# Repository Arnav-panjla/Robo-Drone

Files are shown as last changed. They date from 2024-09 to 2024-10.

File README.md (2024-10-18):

# Drone Project 🚀

Welcome to the Drone Project, developed by the Robotics Club at IIT Delhi. This project showcases a fully custom drone built from scratch, featuring 3D-printed chassis, custom motor drivers, and a custom remote controller.
  <br>
  <br>
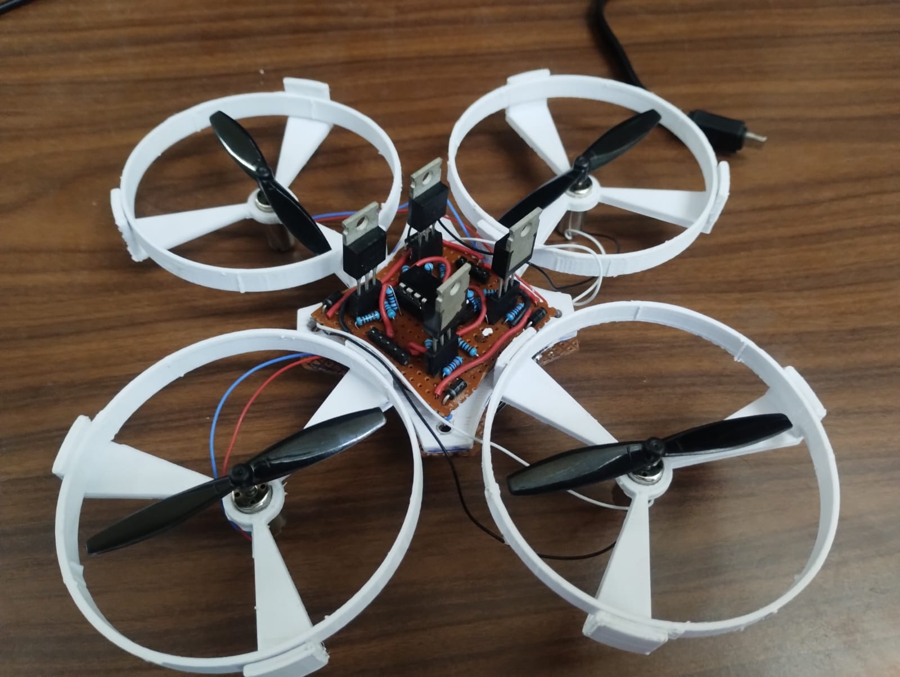
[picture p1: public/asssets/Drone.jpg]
Drone
  
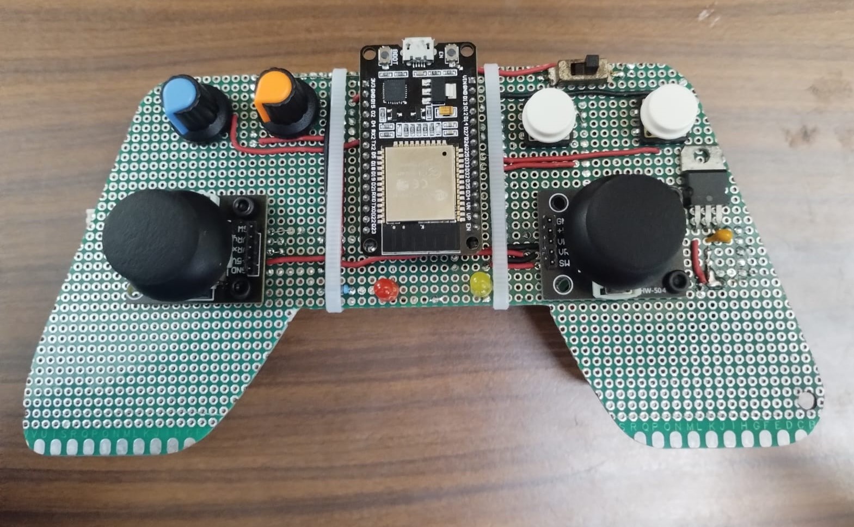
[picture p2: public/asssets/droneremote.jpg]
Motor Driver
  
  <br>

## Table of Contents 📚
- [Introduction](https://github.com/Arnav-panjla/Robo-Drone/blob/main/README.md#introduction-)
- [Components](https://github.com/Arnav-panjla/Robo-Drone/blob/main/README.md#components-%EF%B8%8F)
- [Design and Architecture](https://github.com/Arnav-panjla/Robo-Drone/blob/main/README.md#design-and-architecture-%EF%B8%8F)
- [Functionality](https://github.com/Arnav-panjla/Robo-Drone/blob/main/README.md#functionality-%EF%B8%8F)
- [Theory Used](https://github.com/Arnav-panjla/Robo-Drone/blob/main/README.md#theory-used-)
- [Usage](https://github.com/Arnav-panjla/Robo-Drone/blob/main/README.md#usage-)
- [Contributions](https://github.com/Arnav-panjla/Robo-Drone/blob/main/README.md#contributions-)
- [License](https://github.com/Arnav-panjla/Robo-Drone/blob/main/README.md#license-)
- [Acknowledgements](https://github.com/Arnav-panjla/Robo-Drone/blob/main/README.md#acknowledgements-)

## Introduction 🌟

The drone is designed to be a versatile platform for exploring robotics, remote control, and sensor integration. At its core, the drone utilizes an ESP32-C3 module for communication and control, enabling advanced features such as PID control and integration with a BMX160 sensor for enhanced stability and performance.

## Components 🛠️

- **Chassis**: 3D-printed design for a lightweight and durable structure.
- **Microcontroller**: Xiao ESP32-C3 for receiving signals and controlling motors.
- **Motor Drivers**: Custom-built motor drivers using operational amplifiers (op-amps) and N-channel MOSFETs.
- **Remote Controller**: Built with an ESP32, joystick module, and switches for intuitive control.
- **Sensors**: PID controller and BMX160 sensor for improved stability and performance.

## Design and Architecture 🖥️

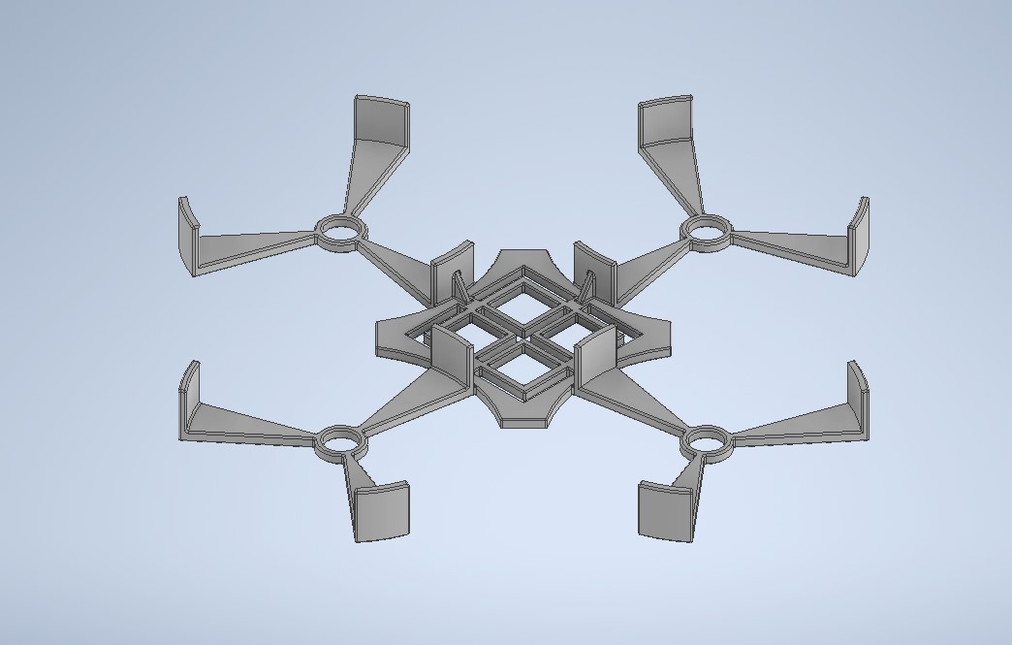
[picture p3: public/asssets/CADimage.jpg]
CADimage


- **Communication**: The drone and remote controller communicate via Wi-Fi, utilizing the ESP32’s capabilities.
- **Motor Control**: PWM signals generated by the ESP32 are amplified by op-amps and used to drive the motors through N-channel MOSFETs.
- **Control Logic**: Implemented PID control for precise maneuvering and stability.
- **posotion calibration**: Done by BMX160 measurment and subsequently using kalman filter.

## Functionality ✈️

- **Remote Control**: Control the drone using a joystick and switches on the remote controller.
- **Stability and Responsiveness**: Utilizes PID control and BMX160 sensor feedback filtered thruogh kalman filter to maintain stable flight.
- **Customizability**: Fully customizable components for future modifications and enhancements.

## Theory Used 📚

In addition to fundamental principles of electronics and mechanics, several advanced concepts were utilized in the development of this project:

- **PID Control**
- **Kalman Filter**
- **PCB designing**
- **Quadcopter Mechanics**
- **3D Design**
- **ESP32 Wi-Fi Communication**

These theories and technologies collectively contributed to the successful implementation and performance of the drone project.

## Usage 📡

1. Power on the drone and remote controller.
2. Connect the remote controller to the drone's Wi-Fi network.
3. Use the joystick remote to control the drone's movements.

## Contributions 🤝

We welcome contributions from anyone interested in enhancing this project! To contribute:

## License 📜

This project is licensed under the MIT License. See the [LICENSE](LICENSE) file for more details.

## Acknowledgements 🙏

- Special thanks to the Robotics Club at IIT Delhi for their support and collaboration.
- I would like to thank the following friends for their invaluable help in building this repository:
    - [Lakshay Bhatnagar](https://github.com/Lakshya-bh) 
    - [Rishima Chaturvedi](https://github.com/friendusername)
- Inspired by various open-source projects in the robotics community.

---

Feel free to reach out if you have any questions or need assistance! 😊

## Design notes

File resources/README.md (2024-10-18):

# Resources 📚

This section contains useful resources, including datasheets and manuals for the components used in the Drone Project.

## Internal Links 🔗

- **LM324 1GHz Opamp**: [LM324 Datasheet](./LM324.PDF)
  <br>
  <br>
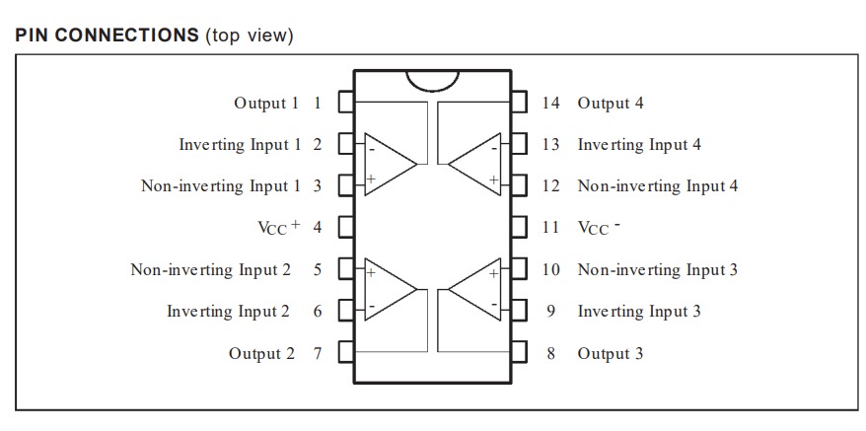
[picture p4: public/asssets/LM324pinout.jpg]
ESP32 Pinout
  

- **IRFZ44N n-channel mosfet**: [IRFZ444N Datasheet](./IRFZ44N.PDF)
  <br>
  <br>
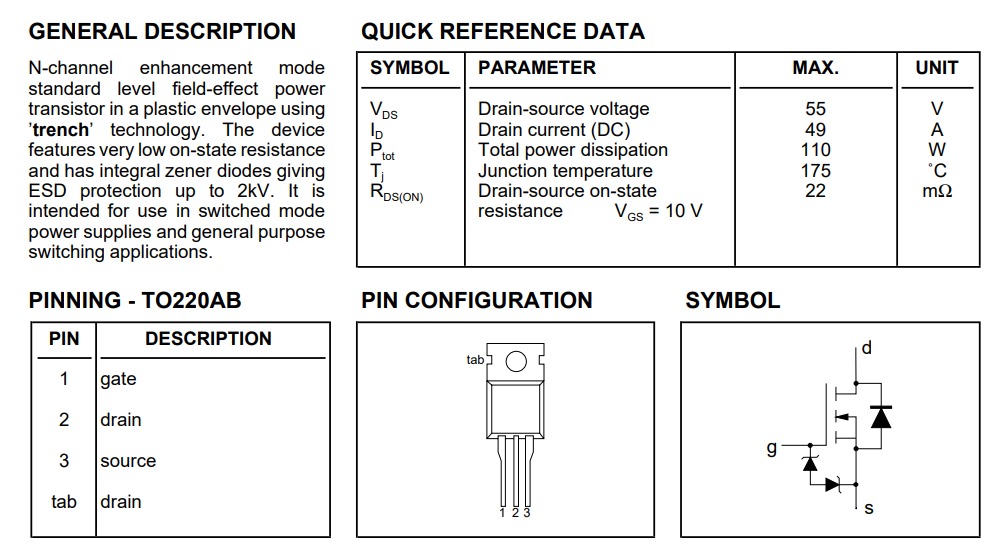
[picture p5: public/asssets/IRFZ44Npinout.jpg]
ESP32 Pinout
  

- **BMX160 Sensor Datasheet**: [BMX160 Sensor Datasheet](./BMX160datasheet.pdf)

## External Links 🌐

- **ESP32**:  [offical espressif ESP32 Manual](https://www.espressif.com/en/products/devkits/esp32-devkitc)
  <br>
  <br>
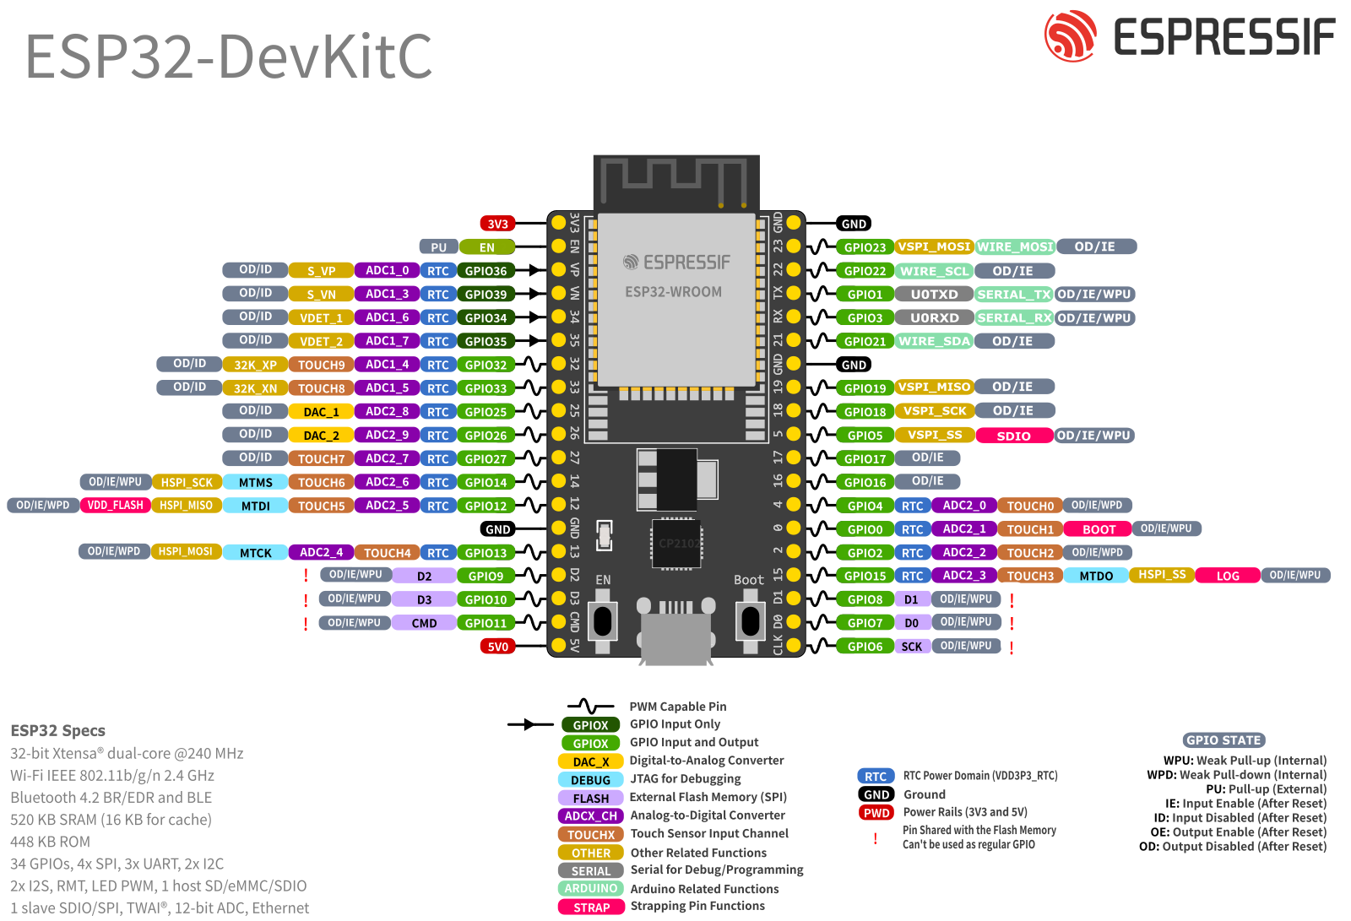
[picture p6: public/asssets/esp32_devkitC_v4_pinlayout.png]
  

- **ESP32-C3**:  [offical XiaoESP32C3 Manual](https://wiki.seeedstudio.com/XIAO_ESP32C3_Getting_Started/)
  <br>
  <br>
ESP32-C3 Pinout
  

- **Oscilloscope Manual**: [Oscilloscope User Manual](./sds5032ev_user_manual.pdf)

- **PID Control Theory**: to be added

## Additional Resources 📖

- **Remote Design**: [How to mechatronics custom rc controller project](https://howtomechatronics.com/projects/diy-arduino-rc-receiver/)

Feel free to explore these resources to enhance your understanding and capabilities in working with the Drone Project!

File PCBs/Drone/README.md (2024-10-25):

#  Drone Driver Circuit

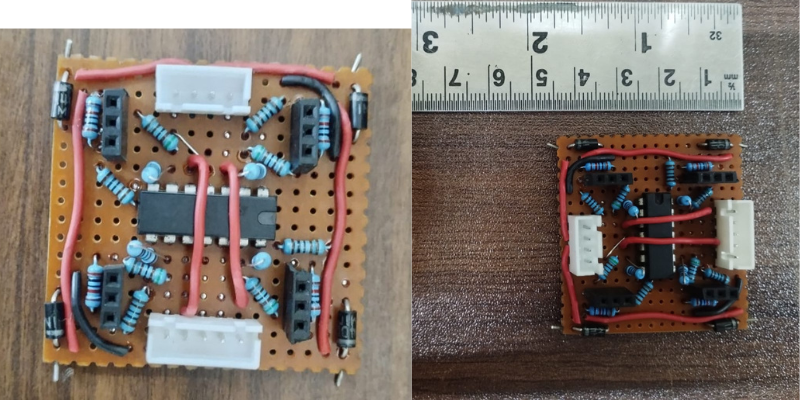
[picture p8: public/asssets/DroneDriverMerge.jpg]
Motor Driver


<!-- ## 📚 Table of Contents
1. [Introduction](#introduction)
2. [Necessity of Creating the Motor Driver](#necessity-of-creating-the-motor-driver)
3. [Testing Video](#testing-video)
4. [Circuit Overview](#circuit-overview)
   - [Motor Driver Circuit](#motor-driver-circuit)
   - [Complete Circuit with ESP32](#complete-circuit-with-esp32)
5. [Components List](#components-list)
6. [Schematic Diagrams](#schematic-diagrams)
   - [Motor Driver Circuit Schematic](#motor-driver-circuit-schematic)
   - [Complete Circuit Schematic](#complete-circuit-schematic)
7. [Connections and Pinouts](#connections-and-pinouts)
8. [Operation and Safety Precautions](#operation-and-safety-precautions)
9. [Future Improvements](#future-improvements)
10. [References](#references) -->

---

## 1. 📝 Introduction

This README provides detailed information about the motor driver circuit designed for controlling four propellers of a drone using an ESP32 microcontroller. The motor driver circuit can handle up to 3.3A at maximum load and operates a 3.7V motor in a single direction.

---

## 2. 🛠️ Necessity of Creating the Motor Driver
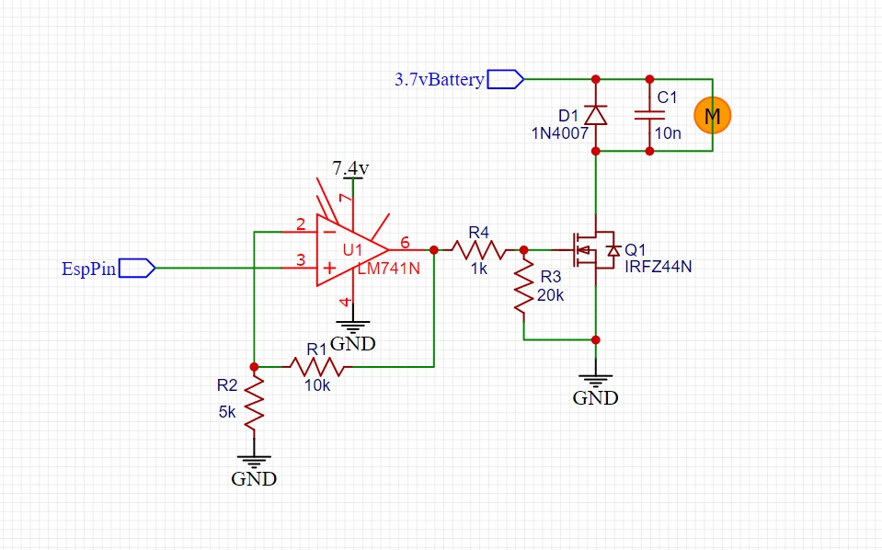
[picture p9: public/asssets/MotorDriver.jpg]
Motor Driver

<br>
The development of this motor driver circuit is essential for several reasons:

- **High Current Handling**: This motor driver can handle up to 3.3A, which is unmatched by other drivers in the market within this price range, making it an economical yet powerful solution for drone applications.

- **Optimization for Drones**: The design is fully optimized for drone operations, ensuring efficient control of the motors under varying loads and conditions.

- **Signal Amplification**:
  <br>
  <br>
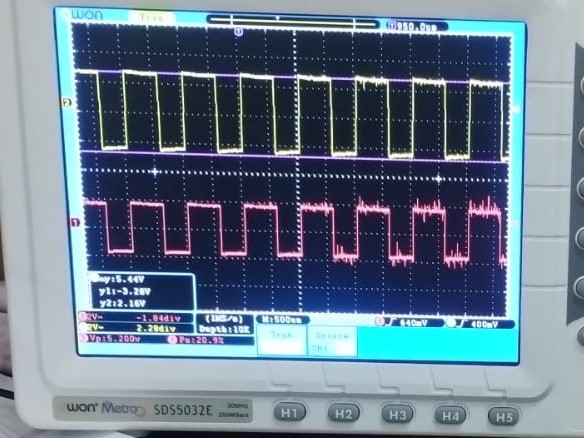
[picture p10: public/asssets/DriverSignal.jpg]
Motor Driver
  
  <br>
 The 3.3V output from the ESP32 was insufficient to drive the MOSFETs directly. To address this, we incorporated an operational amplifier (op-amp) with a non-inverting gain of 1.5. This setup amplifies the 3.3V signal to approximately 5V, effectively driving the MOSFETs and consequently powering the drone motors.

---

## 3. 🎥 Testing Video

To see the motor driver in action, check out the video of our testing process:

[Watch the Testing Video](..\..\public\asssets\DriverTestingVideo.mp4")

In this video, we demonstrate the operation of the motor driver, showcasing its performance and the control of the drone motors.

---

## 4. ⚙️ Circuit Overview

### Motor Driver Circuit: [Motor Driver Schematics PDF](./MotorDriverSchematics.pdf)

The motor driver circuit interfaces with the ESP32 to control the speed and operation of a 3.7V motor. The circuit utilizes MOSFETs or a dedicated motor driver IC for efficient power management.

- **Voltage**: 3.7V and 7.4V for powering op-amps
- **Current**: Up to 3.3A

### Complete Circuit with ESP32 [Motor Driver Schematics PDF](./DroneDriverSchematics.pdf)

The complete circuit integrates the ESP32S# microcontroller, controlling the four motor driver circuits with PWM signals.

---

## 5. 🔧 Components List

| Component | Quantity | Description |
|---|---|---|
| ESP32S3 | 1 | Microcontroller |
| op-AMP | 4 | Part of motor driver circuit |
| N-channel MOSFET | 4 | For motor control |
| Resistors | Various  | Pull-down and for op-amps |
| Capacitors | 4 | Decoupling and filtering |
| Diodes | 4 | Flyback diodes for protection |
| Connectors | Various  | For connecting motors and power |
| Power Supply | 2 | 3.7V batteries |
| PCB | 1 | Custom PCB designed in EasyEDA  |

---

## 6. 📐 Complete Schematic Diagrams

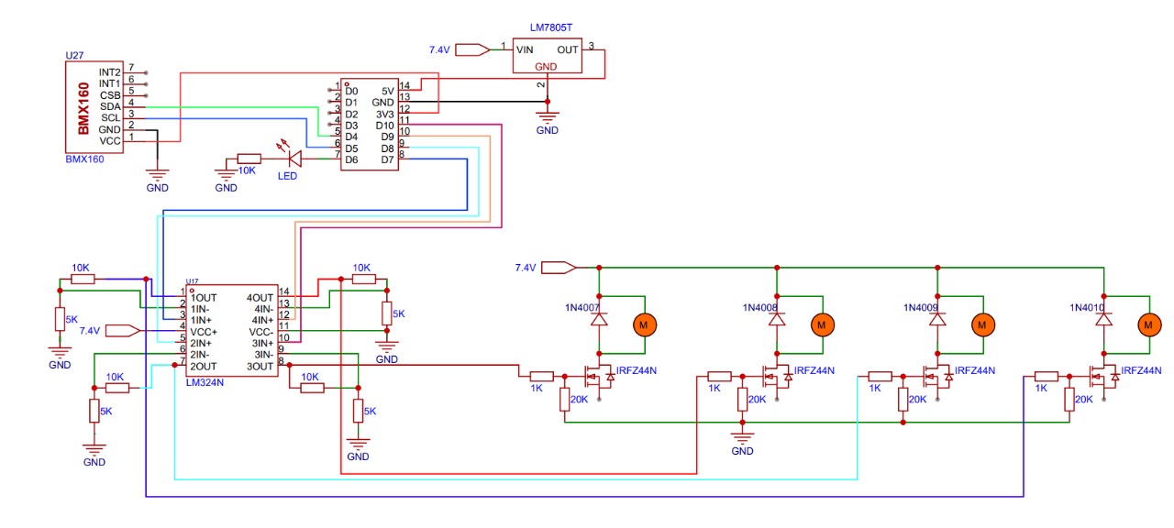
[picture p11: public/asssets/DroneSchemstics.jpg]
Drone Schematics


---

## 7. 🔌 Connections and Pinouts

### ESP32 Pinouts

- **GPIO Pins**: Used for PWM control of the motor drivers.
- **Power Supply**: Connect to the appropriate power source (3.7V).

### Motor Driver Connections

- **Input Pins**: Connect to the corresponding GPIO pins of the ESP32.
- **Motor Terminals**: Connect to the propellers.
- **Power Connections**: Ensure correct voltage and current ratings are followed.

---

## 8. ⚡ Operation and Safety Precautions

- The ESP32 sends PWM signals to the motor drivers to control the speed and operation of each motor.
- Ensure that the code is properly uploaded to the ESP32 to manage motor functions as desired.

### Safety Precautions
- Ensure all connections are secure to prevent shorts.
- Beware of heating of MOSFETs, heatsink not used therefore avoid continuous usage.
- Double-check component ratings to avoid damage.

---

## 9. 🚀 Future Improvements

- Consider adding a speed feedback mechanism for better control.
- Explore options for direction control (e.g., H-bridge configuration).
- Explore professional PCB milling.
- Implement wireless control features using ESP32 capabilities.

---

## 10. 📖 References

- Check out [resources](../../resources/) repository.

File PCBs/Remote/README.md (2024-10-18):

# Remote PCB for Drone Control 🚀
  <br>
  Motor Driver
  <br>

## Overview

This repository contains the design and documentation for a remote PCB used to control a self-made drone. The remote features an ESP32 microcontroller, two joysticks, two potentiometers, two buttons, and onboard LEDs to indicate the success or failure of signal transmission. The system is powered by a 2S battery, with voltage regulation to ensure stable operation.

## Components 🛠️

- **Microcontroller**: ESP32
- **Input Devices**: 
  - 2 Joysticks
  - 2 Potentiometers
  - 2 Buttons
- **LED Indicators**: For success/failure of signal transmission
- **Power Supply**: 
  - 2S LiPo Battery
  - Voltage regulator: LM7806 (step down to 6V) and onboard voltage converter to 3.3V

## Features 🌟

- **Real-time Control**: The joysticks allow for precise control of the drone's movements.
- **Adjustable Parameters**: Potentiometers can be used to adjust flight parameters such as speed and altitude.
- **Status Indication**: Onboard LEDs provide visual feedback on signal status.
- **Compact Design**: Optimized for integration with a drone.

## Schematic 🖼️

  <br>
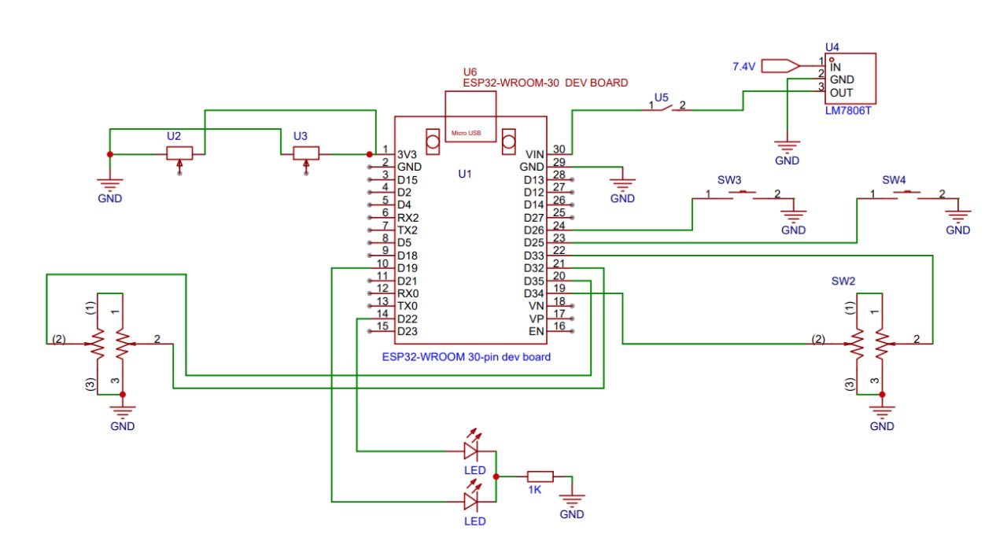
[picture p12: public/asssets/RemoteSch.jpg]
  
  <br>

## Wiring Diagram 🖼️

  <br>
  Motor Driver
  <br>*

## Setup Instructions ⚙️

1. **Power Connection**:
   - Connect a 2S LiPo battery to the power input of the PCB.
   - The LM7806 will step down the voltage to 6V, and the onboard converter will provide 3.3V for the ESP32.

2. **Input Device Connections**:
   - Connect the joysticks and potentiometers to the designated analog input pins on the ESP32.
   - Connect the buttons to digital input pins.

3. **LED Connections**:
   - Connect the LEDs to appropriate GPIO pins for status indication.

4. **Programming the ESP32**:
   - Use the Arduino IDE or PlatformIO to upload the control code to the ESP32.
   - Ensure the necessary libraries for the ESP32 and input devices are installed.

## Usage 🎮

1. Power on the remote by connecting the 2S battery.
2. The onboard LEDs will indicate the power status and signal transmission status.
3. Use the joysticks to control the drone's movements and the potentiometers to adjust flight settings.
4. Press the buttons for additional functionalities (e.g., takeoff, landing).

## Troubleshooting 🔧

- **LEDs Not Lighting Up**: Check power connections and ensure the battery is charged.
- **Signal Transmission Issues**: Verify the connections to the ESP32 and the antennas if used.
- **Unresponsive Inputs**: Ensure that the joysticks and potentiometers are connected properly.

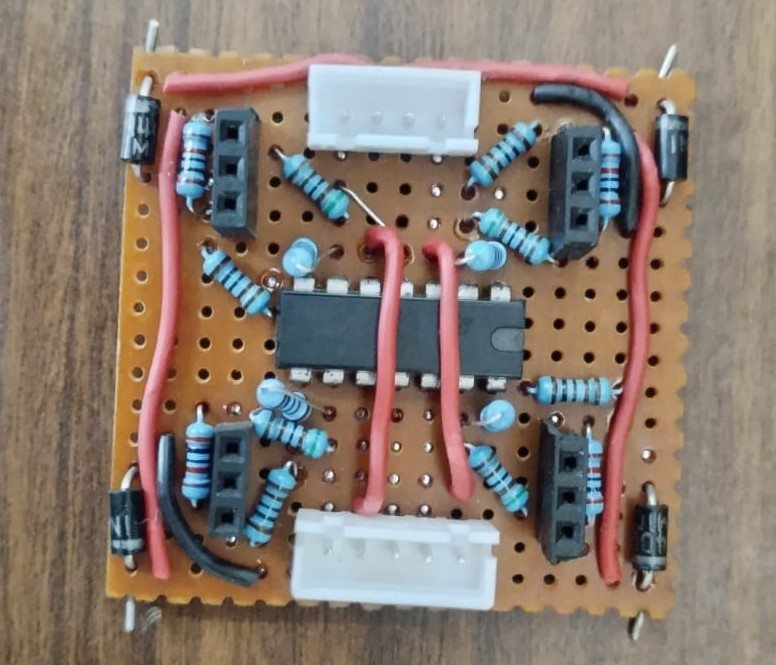
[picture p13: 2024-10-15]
public/asssets/DroneDriver.jpg

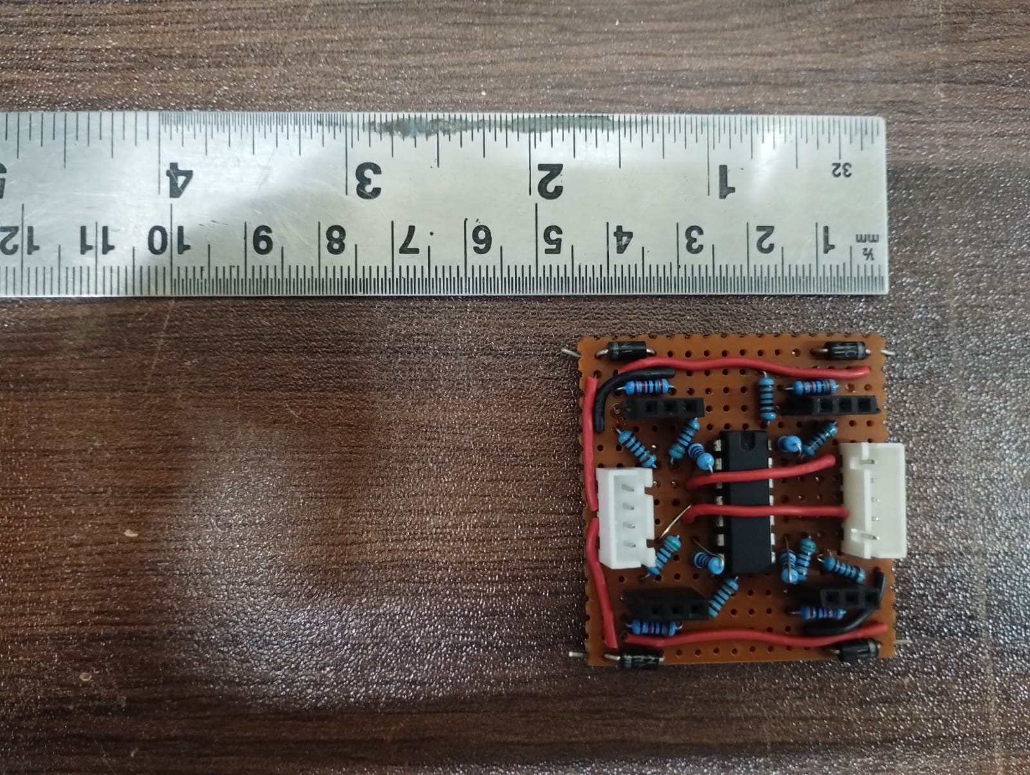
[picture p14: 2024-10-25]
public/asssets/MotorDriverSize.jpeg

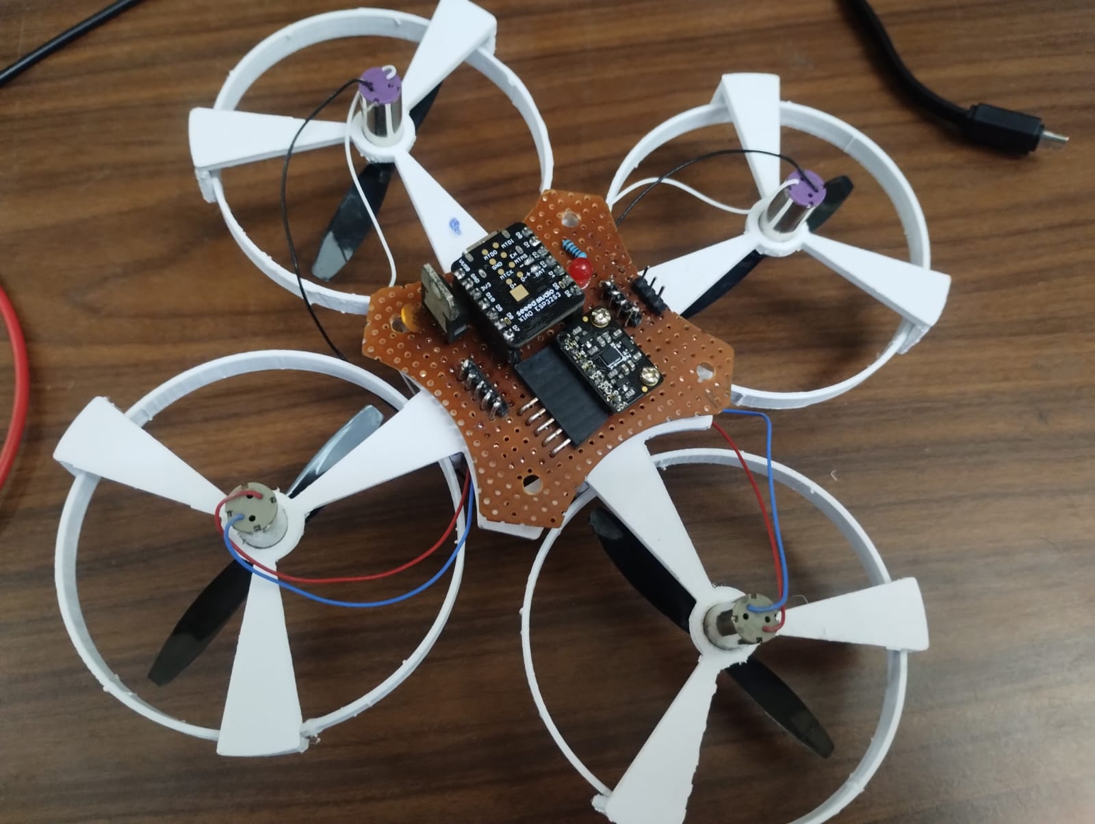
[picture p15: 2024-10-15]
public/asssets/Drone1.jpg

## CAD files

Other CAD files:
CAD/chassis v1.ipt
CAD/ring v3.ipt

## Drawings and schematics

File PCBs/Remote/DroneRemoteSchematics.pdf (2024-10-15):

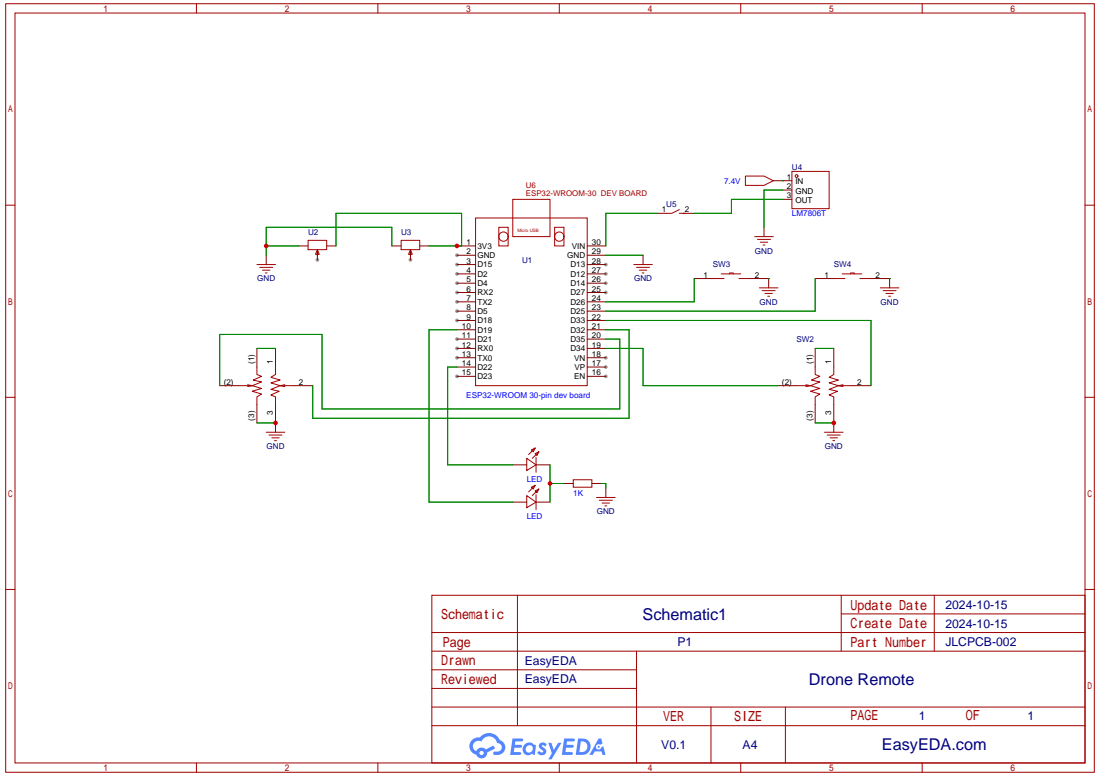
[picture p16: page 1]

ESP32-WROOM 30-pin dev board

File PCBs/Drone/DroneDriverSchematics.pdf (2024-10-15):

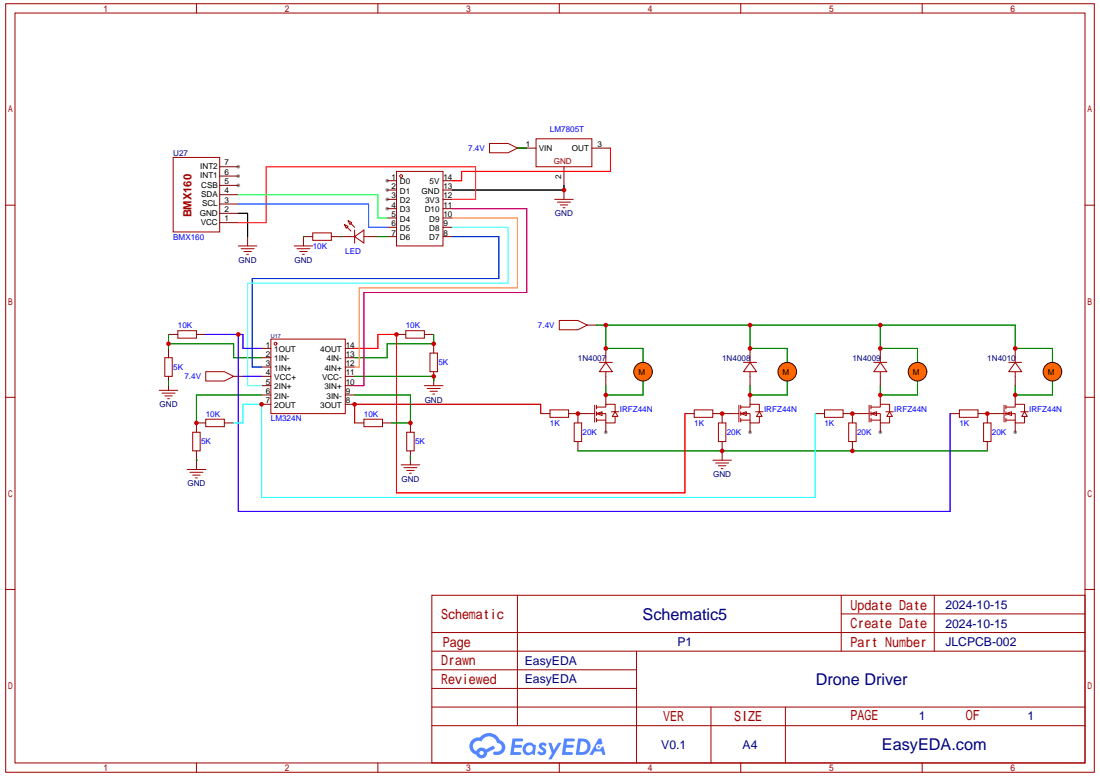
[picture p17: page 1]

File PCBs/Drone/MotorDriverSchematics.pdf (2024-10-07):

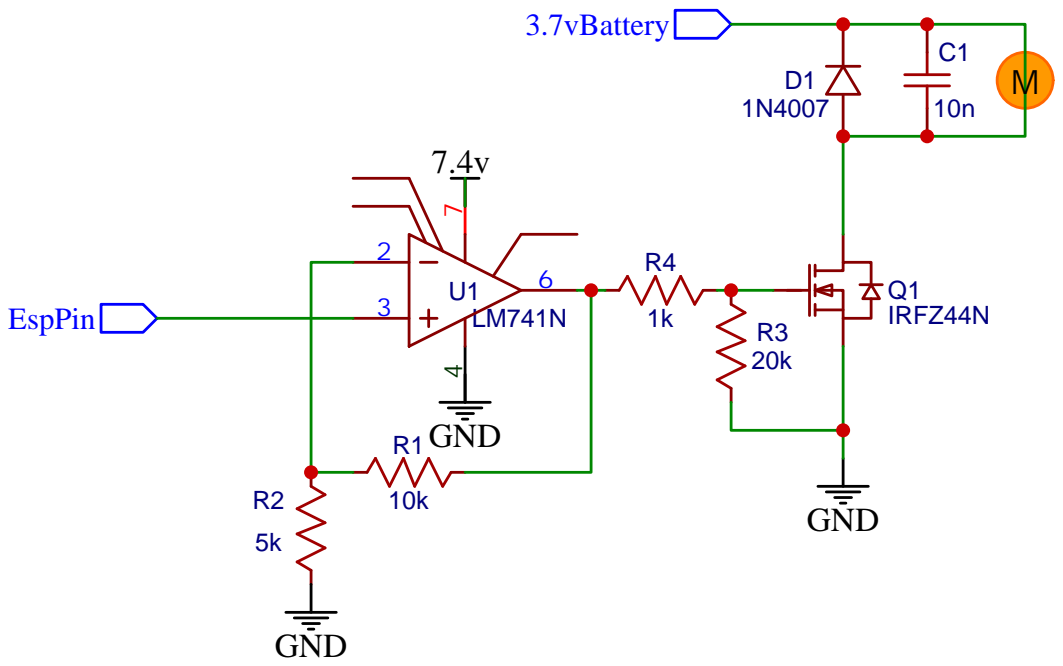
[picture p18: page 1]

Company: Robotics Club IITD

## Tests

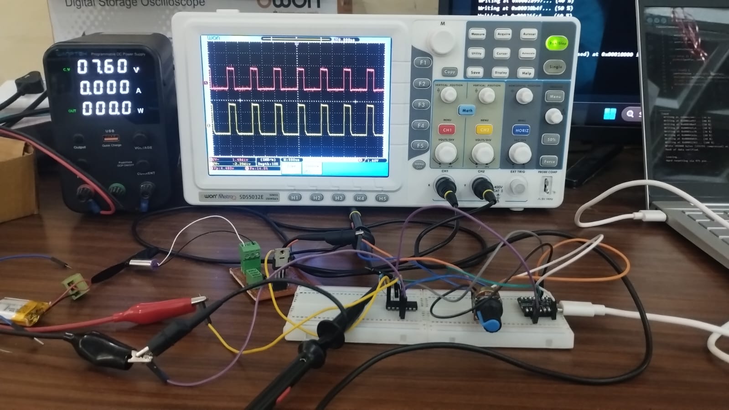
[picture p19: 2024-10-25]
public/asssets/MotorDriverTesting.jpeg

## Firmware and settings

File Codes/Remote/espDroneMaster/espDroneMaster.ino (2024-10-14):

#include <esp_now.h>
#include <WiFi.h>

#define PotPIN 36
#define Y_AXIS_PIN 35
#define BUTTON_PIN 23
#define LED_PIN 19      // LED that indicates everything is fine
#define ERROR_LED_PIN 22 // LED that indicates an error
#define ESPNOW_WIFI_CHANNEL 6

uint8_t broadcastAddress[] = {0xFF, 0xFF, 0xFF, 0xFF, 0xFF, 0xFF};

void OnDataSent(const uint8_t *mac_addr, esp_now_send_status_t status) {
    Serial.print("Last Packet Send Status: ");
    Serial.println(status == ESP_NOW_SEND_SUCCESS ? "Delivery Success" : "Delivery Fail");
}

void setup() {
    Serial.begin(115200);
    pinMode(BUTTON_PIN, INPUT_PULLUP);
    pinMode(LED_PIN, OUTPUT);      // Set LED pin as output
    pinMode(ERROR_LED_PIN, OUTPUT); // Set error LED pin as output
    
    digitalWrite(LED_PIN, HIGH);    // Turn on LED initially to indicate everything is fine
    digitalWrite(ERROR_LED_PIN, LOW); // Ensure error LED is off initially

    WiFi.mode(WIFI_STA);
    WiFi.setChannel(ESPNOW_WIFI_CHANNEL);

    if (esp_now_init() != ESP_OK) {
        Serial.println("Error initializing ESP-NOW");
        digitalWrite(LED_PIN, LOW);      // Turn off LED indicating normal operation
        digitalWrite(ERROR_LED_PIN, HIGH); // Turn on error LED
        ESP.restart();
    }

    esp_now_register_send_cb(OnDataSent);
    
    esp_now_peer_info_t peerInfo;
    memset(&peerInfo, 0, sizeof(peerInfo));
    memcpy(peerInfo.peer_addr, broadcastAddress, sizeof(broadcastAddress));
    peerInfo.channel = ESPNOW_WIFI_CHANNEL;
    peerInfo.encrypt = false;

    if (esp_now_add_peer(&peerInfo) != ESP_OK) {
        Serial.println("Error adding broadcast peer");
        digitalWrite(LED_PIN, LOW);       // Turn off LED indicating normal operation
        digitalWrite(ERROR_LED_PIN, HIGH); // Turn on error LED
        ESP.restart();
    }

    Serial.println("Master setup complete. Broadcasting data...");
}

void loop() {
    char data[32];
    int potVal = analogRead(PotPIN);
    int yVal = analogRead(Y_AXIS_PIN);
    int buttonVal = digitalRead(BUTTON_PIN);

    // Combine data into a single value, you could also use a struct for more complex data
    int val = (9 * map(potVal, 0, 4095, 4095, 0) / 10) + (yVal / 10);

    snprintf(data, sizeof(data), "%d,%d", val, buttonVal);

    if (esp_now_send(broadcastAddress, (uint8_t *)data, sizeof(data)) == ESP_OK) {
        Serial.print("Broadcasting Val: ");
        Serial.println(data);
    } else {
        Serial.println("Failed to send data");
        digitalWrite(LED_PIN, LOW);        // Turn off LED indicating normal operation
        digitalWrite(ERROR_LED_PIN, HIGH); // Turn on error LED on send failure
    }

    delay(200);  // Broadcast every 200 milliseconds
}

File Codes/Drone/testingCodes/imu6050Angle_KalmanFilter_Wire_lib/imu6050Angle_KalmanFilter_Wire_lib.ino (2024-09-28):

# include <Wire.h>

float AccX, AccY, AccZ;
float AngleRoll, AnglePitch, AngleYaw;
float RateRoll, RatePitch, RateYaw;

uint32_t LoopTimer;

// Kalman values
float KalmanAngleRoll = 0;
float KalmanUncertaintyAngleRoll = 2 * 2;
float KalmanAnglePitch = 0;
float KalmanUncertaintyAnglePitch = 2 * 2;
float KalmanFilterOutput[] = {0, 0};

// Variables for calibration
float RateCalibrationRoll = 0;
float RateCalibrationPitch = 0;
float RateCalibrationYaw = 0;
int RateCalibrationNumber = 0;


const float PIE = 3.14159;


// values to be added
const float AccXerr = -0.09;
const float AccYerr = -0.01;
const float AccZerr = -0.84;




void gyro_signals(void){
  //switch on low pass filter
  Wire.beginTransmission(0x68);
  Wire.write(0x1A);
  Wire.write(0x05);
  Wire.endTransmission();

  Wire.beginTransmission(0x68);
  Wire.write(0x1C);
  Wire.write(0x10); // ASF_SEL range 2 -> 8g
  Wire.endTransmission();

  Wire.beginTransmission(0x68);
  Wire.write(0x3B);
  Wire.endTransmission();
  Wire.requestFrom(0x68,6);
  int16_t AccXLSB = Wire.read()<<8 | Wire.read();
  int16_t AccYLSB = Wire.read()<<8 | Wire.read();
  int16_t AccZLSB = Wire.read()<<8 | Wire.read();
  // convert acclerometer measurments
  AccX = (float)AccXLSB/4096 + AccXerr;
  AccY = (float)AccYLSB/4096 + AccYerr;
  AccZ = (float)AccZLSB/4096 + AccZerr;

  //converting accleration values to angles
  AngleRoll = atan(AccY/sqrt(AccX*AccX+AccZ*AccZ))/(PIE/180);
  AnglePitch = atan(AccX/sqrt(AccY*AccY+AccZ*AccZ))/(PIE/180);


  // gyro output and pull rotaion rate measurments
  Wire.beginTransmission(0x68);
  Wire.write(0x1B);
  Wire.write(0x8);
  Wire.endTransmission();
  Wire.beginTransmission(0x68);
  Wire.write(0x43);
  Wire.endTransmission();
  Wire.requestFrom(0x68,6);
  int16_t GyroX = Wire.read()<<8 | Wire.read();
  int16_t GyroY = Wire.read()<<8 | Wire.read();
  int16_t GyroZ = Wire.read()<<8 | Wire.read();
  // converting gyro measurments
  RateRoll = (float)GyroX/65.5;
  RatePitch = (float)GyroY/65.5;
  RateYaw = (float)GyroZ/65.5;
  
}

void kalmanFilter(float& KalmanState, float& KalmanUncertainty, float KalmanInput, float KalmanMeasurement) {
  KalmanState = KalmanState + 0.004 * KalmanInput;
  KalmanUncertainty = KalmanUncertainty + 0.004 * 0.004 * 4 * 4;
  float KalmanGain = KalmanUncertainty / (KalmanUncertainty + 3 * 3);
  KalmanState = KalmanState + KalmanGain * (KalmanMeasurement - KalmanState);
  KalmanUncertainty = (1 - KalmanGain) * KalmanUncertainty;
  KalmanFilterOutput[0] = KalmanState;
  KalmanFilterOutput[1] = KalmanUncertainty;
}

void setup() {
  // put your setup code here, to run once:
  Serial.begin(115200);
  pinMode(13,OUTPUT);
  digitalWrite(13,LOW);
  Wire.setClock(4000000);
  Wire.begin();
  delay(250);
  Wire.beginTransmission(0x68);
  Wire.write(0x6B);
  Wire.write(0x00);
  Wire.endTransmission();

  for (RateCalibrationNumber=0; RateCalibrationNumber<2000; RateCalibrationNumber ++) {
    gyro_signals();
    RateCalibrationRoll+=RateRoll;
    RateCalibrationPitch+=RatePitch;
    RateCalibrationYaw+=RateYaw;
    delay(1);
  }
  RateCalibrationRoll/=2000;
  RateCalibrationPitch/=2000;
  RateCalibrationYaw/=2000;
  digitalWrite(13,HIGH);

}



void loop() {
  // put your main code here, to run repeatedly:
  gyro_signals();
  RateRoll-=RateCalibrationRoll;
  RatePitch-=RateCalibrationPitch;
  RateYaw-=RateCalibrationYaw;
  kalmanFilter(KalmanAngleRoll, KalmanUncertaintyAngleRoll, RateRoll, AngleRoll);
  KalmanAngleRoll=KalmanFilterOutput[0]; 
  KalmanUncertaintyAngleRoll=KalmanFilterOutput[1];
  kalmanFilter(KalmanAnglePitch, KalmanUncertaintyAnglePitch, RatePitch, AnglePitch);
  KalmanAnglePitch=KalmanFilterOutput[0]; 
  KalmanUncertaintyAnglePitch=KalmanFilterOutput[1];



  // Serial.print("AccX = ");
  // Serial.print(AccX);
  // Serial.print("  AccY = ");
  // Serial.print(AccY);
  // Serial.print("  AccZ = ");
  // Serial.print(AccZ);
  Serial.print("  Roll Angle [°] ");
  Serial.print(KalmanAngleRoll);
  Serial.print("  Pitch Angle [°] ");
  Serial.println(KalmanAnglePitch);
  
  
  while (micros() - LoopTimer < 10000);
  LoopTimer = micros();

}

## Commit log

2024-09-28 added basic files and readmes
    [aaa v1.ipt, ring v3.ipt]
2024-09-28 minor adjustments
    [chassis v1.ipt]
2024-09-28 changed cad image
2024-10-07 added motor Driver
2024-10-14 updater ESP32slave
2024-10-14 modified slave and master code, with LED feature
